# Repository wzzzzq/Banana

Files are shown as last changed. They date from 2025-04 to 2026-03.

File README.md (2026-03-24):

# Banana_Bot

基于 Arduino 的四轮麦克纳姆轮全向移动底盘 + 6自由度机械臂遥控机器人。

Banana_Bot 运行演示

## 项目简介

Banana_Bot 是一台面向机械赛的遥控机器人，具备全向移动和物体抓取能力。整车由两块 Arduino 分别控制底盘和机械臂，通过串口通信协调工作，操作员使用 SBUS 遥控器进行控制。

### 主要特性

- 麦克纳姆轮全向移动（前后、横移、自转）
- 6自由度机械臂，支持多种预设抓取/放置动作
- SBUS 遥控协议，低延迟高可靠
- 遥控器失联自动停车保护（Failsafe）

## 系统架构

```
┌────────────┐   SBUS    ┌─────────────────┐  Serial3  ┌─────────────────┐
│   遥控器    │ ────────> │    底盘主控       │ ────────> │   机械臂主控      │
│ (SBUS TX)  │           │ (Arduino Mega)  │ (9600bps) │   (Arduino)     │
└────────────┘           └────────┬────────┘           └────────┬────────┘
                                  │                             │
                         ┌────────┴────────┐           ┌────────┴────────┐
                         │   TB6612FNG     │           │   6路舵机        │
                         │   四路电机驱动    │           │   控制器          │
                         └────────┬────────┘           └────────┬────────┘
                                  │                             │
                    ┌─────────────┼─────────────┐      ┌────────┴────────┐
                    │             │             │      │  Learm 6DOF     │
                ┌───┴───┐   ┌────┴────┐   ┌────┴───┐   │  机械臂          │
                │ MG513 │   │  MG513  │   │ MG513  │   │  (6×舵机)        │
                │  ×4   │   │  编码器  │   │  霍尔   │   └─────────────────┘
                └───┬───┘   └────┬────┘   └────┬───┘
                    │            │             │
                ┌───┴────────────┴─────────────┴───┐
                │    麦克纳姆轮底盘 (75mm×4)          │
                └──────────────────────────────────┘
```

## 软件架构

项目包含两个独立的 Arduino 程序，分别运行在底盘主控和机械臂主控上。

### 底盘控制系统 (`main/`)

```
main/
├── main.ino      # 入口：初始化 + 主循环
├── include.h     # 统一头文件引用
├── App.cpp/.h    # 任务调度与遥控信号解算
├── motor.cpp/.h  # 电机驱动、编码器反馈、PWM 输出
└── signal.cpp/.h # SBUS 协议接收与机械臂指令转发
```

**控制流程：**

```
loop()
 └─> TaskRun()                    [30ms 周期]
      ├─> Write()                 向机械臂发送控制指令
      ├─> GetSignal()             读取 SBUS 遥控器数据
      ├─> graph()                 串口输出调试曲线
      └─> 信号解算
           ├─> failsafe?  ──yes──> stop_all()    紧急停车
           ├─> 油门低/摇杆居中? ──> stop_all()    待机
           └─> 正常控制:
                ├─> ch[1] → 前后速度 (mafor~mdfor)
                ├─> ch[0] → 横移速度 (mago~mdgo)，对角轮反向
                ├─> ch[3] → 自转速度 (maturn~mdturn)，左右侧反向
                └─> 三轴叠加 → ref1~ref4 → setspeed() → moving()
```

**麦克纳姆轮运动学：**

| 运动方向 | M1(左前) | M2(右前) | M3(左后) | M4(右后) |
|---|---|---|---|---|
| 前进 | + | + | + | + |
| 横移(右) | + | - | + | - |
| 自转(顺) | + | + | - | - |

最终每个电机的输出 = 前后分量 + 横移分量 + 自转分量，限幅 ±255。

**电机控制方式：**
- 开环 PWM 直驱，遥控器摇杆量直接映射为 PWM 输出值

### 机械臂控制系统 (`arm code/main/`)

```
arm code/main/
└── main.ino      # 6自由度舵机控制，含串口指令解析与速度插值
```

**控制流程：**

```
loop()
 ├─> GetData()                    解析串口指令 [角度, 动作编号, 夹爪, 辅助]
 ├─> update_state()               根据动作编号查表 → 更新目标角度
 ├─> ServoSetPluseAndTime()       设置目标脉宽与运动时间
 └─> ServoPwmDutyCompare()        每 20ms 步进插值，平滑到达目标位置
```

**预设动作表：**

| 编号 | 动作 | 舵机1 (底座旋转) | 舵机2 (大臂) | 舵机3 (小臂) |
|-----|---|---|---|---|
| 0 | 默认 | 500 | 500 | 500 |
| 1 | 抓球 | 2500 | 1000 | 2000 |
| 2 | 放木块  | 1900 | 600 | 2000 |
| 3 | 投球 | 1200 | 1000 | 1000 |
| 4 | 抓木块  | 2500 | 1200 | 1600 |

**舵机速度控制：**
- 运动时间可调（20ms ~ 30000ms），默认 5000ms
- 采用线性插值，每 20ms 步进一次，确保平滑运动
- PWM 脉宽范围：500μs ~ 2500μs

### 通信协议

底盘主控通过 Serial3 (9600bps) 向机械臂发送 JSON 风格数组指令：

```
[旋转角度, 预设动作编号, 夹爪角度, 辅助角度]
```

示例：
```
[1500,1,1500,1200]    # 底座居中，执行"抓球"动作，夹爪1500μs，辅助1200μs
[1500,0,500,1200]     # 底座居中，默认姿态，夹爪全闭，辅助1200μs
```

遥控器通道映射：
| 遥控器通道 | 功能 | 映射方式 |
|---|---|---|
| ch[0] | 底盘横移 | 340-1704 → PWM ±255 |
| ch[1] | 底盘前后 | 340-1704 → PWM ±255 |
| ch[2] | 油门/使能 | <800 时停车 |
| ch[3] | 底盘自转 | 340-1704 → PWM ±255 |
| ch[4] | 机械臂辅助轴 | 340-1704 → 500-2500μs |
| ch[5] | 机械臂旋转 | 340-1704 → 500-2500μs |
| ch[6] | 夹爪开合 | <1000: 1500μs / 否则: 500μs |
| ch[7] | 动作模式切换 | <1000: 投球模式(3) |
| ch[8] | 动作细选 | <1000: 抓球(1) / <1300: 默认(0) / 否则: 放木块(2) |

## 硬件清单 (BOM)

### 底盘系统

| 组件 | 型号/规格 | 关键参数 | 数量 | 单价 (CNY) | 小计 (CNY) |
|---|---|---|---|---|---|
| 直流减速电机 | MG513 + 霍尔编码器 | 额定电压 12V，减速比 1:30，含 37mm 加厚安装支架 | 4 | 51.8 | 207.2 |
| 麦克纳姆轮 | 75mm 直径，一组4个 | 抱紧式固定联轴器，安装孔径 5mm，配合 MG513 输出轴 | 1组 | 239 | 239 |
| 电机驱动模块 | TB6612FNG 四路驱动 | 已焊接排针，带板载稳压，单路最大 1.2A，峰值 3.2A | 1 | 69 | 69 |
| 电路板支撑柱 | M4×50 六角铜柱 | 双通铜螺柱，用于底盘层间支撑 | 10 | 4.32 | 43.2 |

### 机械臂系统

| 组件 | 型号/规格 | 关键参数 | 数量 | 单价 (CNY) | 小计 (CNY) |
|---|---|---|---|---|---|
| 机械臂套件 | 幻尔 Learm 6自由度 | 散件（仅舵机 + 支架），不含主控，6个总线舵机 | 1套 | 519 | 519 |
| 舵机控制器 | 6路开源舵机控制器 | Arduino 控制板，黑色款，用于驱动 Learm 机械臂 | 1 | 132 | 132 |

### 末端执行器辅材

| 组件 | 用途 | 数量 | 单价 (CNY) | 小计 (CNY) |
|---|-----|---|---|---|
| 百洁布 | 夹爪内侧摩擦面，增大抓取摩擦力 | 1 | 14.8 | 14.8 |
| 橡胶防滑垫 | 夹爪防滑衬垫，防止物体滑落 | 1 | 16.8 | 16.8 |

### 费用汇总

| 类别 | 小计 (CNY) |
|---|---|
| 底盘系统 | 558.4 |
| 机械臂系统 | 651 |
| 末端辅材 | 31.6 |
| **总计** | **1241** |

> **注意**：以上清单不含遥控器、接收机、电池、导线、螺丝等通用耗材。

## 引脚定义

### 底盘主控 (Arduino Mega)

**电机驱动引脚：**

| 电机 | 位置 | PWM | IN1 | IN2 | 编码器A (中断) | 编码器B |
|---|---|-----|-----|-----|---|---|
| M1 | 左前 | D2  | D40 | D42 | D18 (INT.3) | D39 |
| M2 | 右前 | D3  | D44 | D46 | D19 (INT.2) | D36 |
| M3 | 左后 | D4  | D48 | D50 | D20 (INT.1) | D34 |
| M4 | 右后 | D5  | D51 | D52 | D21 (INT.0) | D32 |

**通信引脚：**

| 功能 | 接口 | 波特率 |
|---|---|---|
| 调试串口 | Serial (USB) | 9600 |
| SBUS 遥控输入 | Serial2 (RX2, D17) | 100000 (SBUS标准) |
| 机械臂指令输出 | Serial3 (TX3, D14) | 9600 |

### 机械臂主控

| 舵机编号 | 功能 | Arduino 引脚 |
|---|---|---|
| 0 | 底座旋转 | D10 |
| 1 | 大臂 | A2  |
| 2 | 小臂 | A3  |
| 3 | 腕部俯仰 | A0  |
| 4 | 腕部旋转 | A1  |
| 5 | 夹爪 | D7  |

## 依赖库

| 库名 | 用途 | 安装方式 |
|---|---|---|
| [Servo](https://www.arduino.cc/reference/en/libraries/servo/) | 舵机 PWM 控制 | Arduino IDE 内置 |
| [SBUS](https://github.com/bolderflight/sbus) | SBUS 遥控协议解析 | Library Manager 搜索 "Bolder Flight SBUS" |

## 编译与烧录

1. 安装 [Arduino IDE](https://www.arduino.cc/en/software) (≥1.8)
2. 通过 Library Manager 安装上述依赖库
3. **底盘程序**：打开 `main/main.ino` → 板型选择 `Arduino Mega 2560` → 编译烧录
4. **机械臂程序**：打开 `arm code/main/main.ino` → 板型选择对应 Arduino 板 → 编译烧录
5. 接线完成后上电，遥控器对频即可操控

## 许可证

本项目采用 MIT 许可证，详见 [LICENSE](LICENSE) 文件。

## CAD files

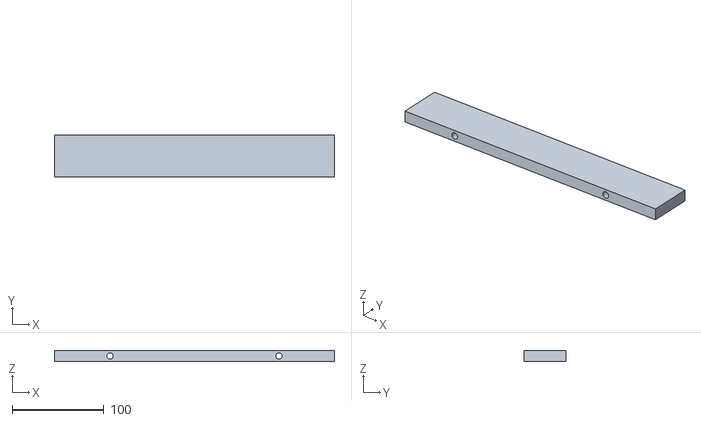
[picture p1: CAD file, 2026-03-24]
CADs/推板.STL
305.0 x 46.0 x 12.0

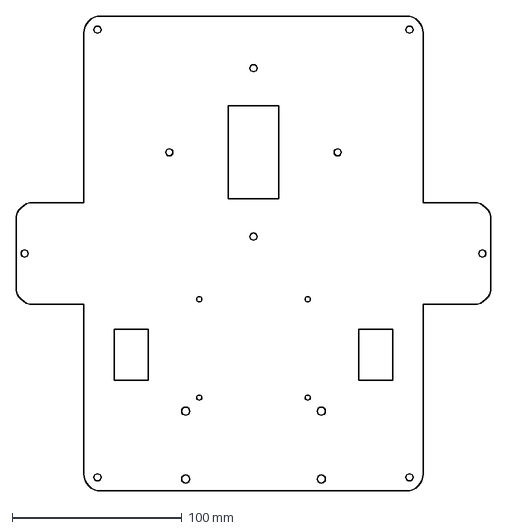
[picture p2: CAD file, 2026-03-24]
CADs/上底盘.DXF
280.0 x 280.0 mm

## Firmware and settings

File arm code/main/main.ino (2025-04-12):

#include <Servo.h>                // 声明调用Servo.h库
#define  SERVO_NUM  6             //舵机数量.0...........................................................3333333333333333333333333333333333333333333333333333333333333333333333333333333333333333333333333333333333333333333
Servo myservo[SERVO_NUM];         //创建六个舵机类
const  byte servo_pin[SERVO_NUM] = {10, A2, A3, A0, A1, 7}; //宏定义舵机控制引脚

int data[10]={1500,0,1500,1200}, cnt, l, num;

int ServoPwmDuty[8] = {1500, 1500, 1500, 1500, 1500, 1500, 1500, 1500}; //PWM脉冲宽度
int ServoPwmDutySet[8] = {1500, 1500, 1500, 1500, 1500, 1500, 1500, 1500}; //PWM脉冲宽度
double ServoPwmDutyInc[8];   //为了速度控制，当PWM脉宽发生变化时，每2.5ms或20ms递增的PWM脉宽

double cx = 93, cy = 61, Kpx = 0.2, Kpy = 0.4,  xnow, ynow;
double angle[10] = {1500, 500, 500, 500, 1500, 1200}; 
double position[5][10]= {{500,500,500}, // 默认
                        {2500, 1000, 2000}, //抓球
                        {1900, 600, 2000}, //放木块
                        {1200,1000,1000}, //投球
                        {2500, 1200, 1600}}; //抓木块

bool ServoPwmDutyHaveChange = 0;  //脉宽有变化标志位[1500,1900, 600, 2000, 1500,1200]
bool found = 0;

int ServoTime = 5000;      //舵机从当前角度运动到指定角度的时间，也就是控制速度

unsigned long t, T;

void ServoSetPluseAndTime(int id, int p, int time)
{
  if (id >= 0 && id < 6 && p >= 500 && p <= 2500)
  {
    if (time < 20)
      time = 20;
    if (time > 30000)
      time = 30000;
    ServoPwmDutySet[id] = p;
    ServoTime = time;
    ServoPwmDutyHaveChange = 1;
  }
}

void ServoPwmDutyCompare(void)//脉宽变化比较及速度控制
{
  int i;

  static int ServoPwmDutyIncTimes; //需要递增的次数
  static bool ServoRunning = 0; //舵机正在以指定速度运动到指定的脉宽对应的位置
  if (ServoPwmDutyHaveChange) //停止运动并且脉宽发生变化时才进行计算      ServoRunning == 0 &&
  {
    ServoPwmDutyHaveChange = 0;
    ServoPwmDutyIncTimes = ServoTime / 20; //当每20ms调用一次ServoPwmDutyCompare()函数时用此句
    for (i = 0; i < 6; i++)
    {
      //if(ServoPwmDuty[i] != ServoPwmDutySet[i])
      {
        if (ServoPwmDutySet[i] > ServoPwmDuty[i])
        {
          ServoPwmDutyInc[i] = ServoPwmDutySet[i] - ServoPwmDuty[i];
          ServoPwmDutyInc[i] = -ServoPwmDutyInc[i];
        }
        else
        {
          ServoPwmDutyInc[i] = ServoPwmDuty[i] - ServoPwmDutySet[i];
        }
        ServoPwmDutyInc[i] /= ServoPwmDutyIncTimes;//每次递增的脉宽
      }
    }
    ServoRunning = 1;  //舵机开始动作
  }
  if (ServoRunning)
  {
    ServoPwmDutyIncTimes--;
    for (i = 0; i < 6; i++)
    {
      if (ServoPwmDutyIncTimes == 0)
      { //最后一次递增就直接将设定值赋给当前值
        ServoPwmDuty[i] = ServoPwmDutySet[i];
        ServoRunning = 0; //到达设定位置，舵机停止运动
      }
      else
      {
        ServoPwmDuty[i] = ServoPwmDutySet[i] + (signed short int)(ServoPwmDutyInc[i] * ServoPwmDutyIncTimes);
      }
      myservo[i].writeMicroseconds(ServoPwmDuty[i]);
    }
  }
}

void update_state(){
  angle[0] = data[0];
  int index=data[1];
  for (int i = 1; i < 4; i++)
  {
    angle[i] = position[index][i-1];
  }
  angle[4] = data[2];
  angle[5] = data[3];
  //for(int i=0;i<6;i++) angle[i]=data[i];
}

void GetData()
{
  found = 0;
  if (Serial.available())
  {
    found = 1;
    char input = Serial.read();
    while (input != '[' && input != -1)   input = Serial.read();
    if (input != -1)
    {
      String s = Serial.readStringUntil(']'), numstr = "";
      l = s.length(), cnt = 0;
      for (int i = 0; i < l; i++)
      {
        if (isDigit(s[i]))
          numstr += s[i];
        if (s[i] == ',' || i == l - 1)
        {
          data[cnt++] = numstr.toInt();
          numstr = "";
        }
      }
    }
    update_state();
  }
}

void PrintData()
{
  for (int i = 0; i < cnt; i++)
  {
    Serial.println(data[i]);
  }
  Serial.println("==========");
}

void setup() {
  //put your setup code here, to run once:
  Serial.begin(9600);
  pinMode(3, INPUT);
  for (byte i = 0; i < SERVO_NUM; i++ ) {
    myservo[i].attach(servo_pin[i]);    // 将10引脚与声明的舵机对象连接起来
  }
  t = millis() + 20;
}

void loop() {
  //put your main code here, to run repeatedly:
  GetData();
  PrintData();
  //if (millis() > t)
  {
    for (int i = 0; i < 6; i++)  ServoSetPluseAndTime(i, angle[i], 60);
    ServoPwmDutyCompare();
    t = millis() + 20;
  }
}

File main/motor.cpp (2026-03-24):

#include "include.h"

bool rev1, rev2, rev3, rev4;
double M1PWMOUT, M2PWMOUT, M3PWMOUT, M4PWMOUT;//motor output
double in1, in2, in3, in4, M1S, M2S, M3S, M4S;//motor input
struct motor
{
  int in1;
  int in2;
  int pwm;
  int A_out;
  int B_out;
};
motor M1, M2, M3, M4;
void macount()
{
  rev1 = digitalRead(M1.B_out);
  in1++;
}
void mbcount()
{
  rev2 = digitalRead(M2.B_out);
  in2++;
}
void mccount()
{
  rev3 = !digitalRead(M3.B_out);
  in3++;
}
void mdcount()
{
  rev4 = !digitalRead(M4.B_out);
  in4++;
}
void moving()
{
  if (M1PWMOUT > 0)
  {
    analogWrite(M1.pwm, M1PWMOUT);
    digitalWrite(M1.in1, 1);
    digitalWrite(M1.in2, 0);
  }
  else
  {
    analogWrite(M1.pwm, abs(M1PWMOUT));
    digitalWrite(M1.in1, 0);
    digitalWrite(M1.in2, 1);
  }
  if (M2PWMOUT > 0)
  {
    analogWrite(M2.pwm, M2PWMOUT);
    digitalWrite(M2.in1, 0);
    digitalWrite(M2.in2, 1);
  }
  else
  {
    analogWrite(M2.pwm, abs(M2PWMOUT));
    digitalWrite(M2.in1, 1);
    digitalWrite(M2.in2, 0);
  }
  if (M3PWMOUT > 0)
  {
    analogWrite(M3.pwm, M3PWMOUT);
    digitalWrite(M3.in1, 0);
    digitalWrite(M3.in2, 1);
  }
  else
  {
    analogWrite(M3.pwm, abs(M3PWMOUT));
    digitalWrite(M3.in1, 1);
    digitalWrite(M3.in2, 0);
  }
  if (M4PWMOUT > 0)
  {
    analogWrite(M4.pwm, M4PWMOUT);
    digitalWrite(M4.in1, 1);
    digitalWrite(M4.in2, 0);
  }
  else
  {
    analogWrite(M4.pwm, abs(M4PWMOUT));
    digitalWrite(M4.in1, 0);
    digitalWrite(M4.in2, 1);
  }
  //Serial.println("moved");
}
void stop_all()
{
  digitalWrite(M1.in1, 1);
  digitalWrite(M2.in1, 1);
  digitalWrite(M3.in1, 1);
  digitalWrite(M4.in1, 1);
  digitalWrite(M1.in2, 1);
  digitalWrite(M2.in2, 1);
  digitalWrite(M3.in2, 1);
  digitalWrite(M4.in2, 1);
  M1PWMOUT = 0;
  M2PWMOUT = 0;
  M3PWMOUT = 0;
  M4PWMOUT = 0;
  ref1 = 0;
  ref2 = 0;
  ref3 = 0;
  ref4 = 0;
}
void fail_safe()
{
  stop_all();
}
void GetM1Speed()
{
  if (rev1)
    M1S = in1;
  else
    M1S = -in1;
  in1 = 0;
}
void GetM2Speed()
{
  if (rev2)
    M2S = in2;
  else
    M2S = -in2;
  in2 = 0;
}
void GetM3Speed()
{
  if (rev3)
    M3S = in3;
  else
    M3S = -in3;
  in3 = 0;
}
void GetM4Speed()
{
  if (rev4)
    M4S = in4;
  else
    M4S = -in4;
  in4 = 0;
}
void Speed()
{
  GetM1Speed();
  GetM2Speed();
  GetM3Speed();
  GetM4Speed();
}
void setspeed()
{
  M1PWMOUT = ref1;
  M2PWMOUT = ref2;
  M3PWMOUT = ref3;
  M4PWMOUT = ref4;
}
void PrintSpeed()
{
  Serial.println(M1S);
  Serial.println(M2S);
  Serial.println(M3S);
  Serial.println(M4S);
  Serial.println("==========");
}
void graph()
{
  Serial.print("reference:");
  Serial.print(ref1);
  Serial.print(",");
  Serial.print("speed:");
  Serial.println(M1S);
}
void InitMotor()
{
  M1.A_out = 18;
  M2.A_out = 19;
  M3.A_out = 20;
  M4.A_out = 21;
  M1.B_out = 39;
  M2.B_out = 36;
  M3.B_out = 34;
  M4.B_out = 32;
  M1.in1 = 40;
  M1.in2 = 42;
  M2.in1 = 44;
  M2.in2 = 46;
  M3.in1 = 48;
  M3.in2 = 50;
  M4.in1 = 51;
  M4.in2 = 52;
  M1.pwm = 2;
  M2.pwm = 3;
  M3.pwm = 4;
  M4.pwm = 5;
  pinMode(M1.pwm, OUTPUT);
  pinMode(M2.pwm, OUTPUT);
  pinMode(M3.pwm, OUTPUT);
  pinMode(M4.pwm, OUTPUT);
  pinMode(M1.in1, OUTPUT);
  pinMode(M1.in2, OUTPUT);
  pinMode(M2.in1, OUTPUT);
  pinMode(M2.in2, OUTPUT);
  pinMode(M3.in1, OUTPUT);
  pinMode(M3.in2, OUTPUT);
  pinMode(M4.in1, OUTPUT);
  pinMode(M4.in2, OUTPUT);
  pinMode(M1.B_out, INPUT);
  pinMode(M2.B_out, INPUT);
  pinMode(M3.B_out, INPUT);
  pinMode(M4.B_out, INPUT);
  pinMode(M1.A_out, INPUT);
  pinMode(M2.A_out, INPUT);
  pinMode(M3.A_out, INPUT);
  pinMode(M4.A_out, INPUT);
  /************/
}

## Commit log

2026-03-24 准备公开发布：完善文档，清理内部文件
    - 重写 README.md：添加项目简介、系统架构、硬件清单(BOM)、引脚定义、
    依赖库、编译烧录说明、通信协议文档
    - 添加 MIT LICENSE
    - 添加 .gitignore（排除 .DS_Store、构建产物、IDE 配置）
    - 移除 .DS_Store（macOS 元数据文件）
    - 移除 workflow.md（内部团队工作分配文档，含个人信息）
    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
2026-03-24 完善 README：更名 Banana_Bot，详化硬件清单与软件架构
    - 标题更名为 Banana_Bot
    - 硬件清单按底盘/机械臂/辅材分类，列出型号、关键参数、单价与小计
    - 添加详细软件架构：控制流程图、麦克纳姆运动学、预设动作表、
    舵机速度控制原理、遥控器通道映射表
    - 补充引脚定义中的中断号和通信波特率
    - 添加依赖库安装方式说明
    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
2026-03-24 移除未使用的 PID 代码，修复系统架构图对齐
    - motor.cpp: 移除 PID_v1.h 引用和 Kp/Ki/Kd 变量（实际为开环 PWM 直驱）
    - README: 移除 PID 相关描述和依赖库，修复 ASCII 架构图竖线对齐
    https://claude.ai/code/session_01Noe6eiG2gT1dzd7t9RjymQ
    [motor.cpp]
2026-03-24 将图片移至 images/ 目录并在 README 中展示
    - 实物照片 → images/banana_bot.jpg
    - 运行演示 → images/banana_bot_demo.gif
    - README 标题下方添加图片展示
    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
2026-03-24 移除静态实物图，仅保留 GIF 演示动图
    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
